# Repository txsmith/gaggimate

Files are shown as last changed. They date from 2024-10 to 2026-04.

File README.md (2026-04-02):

<p align="center">
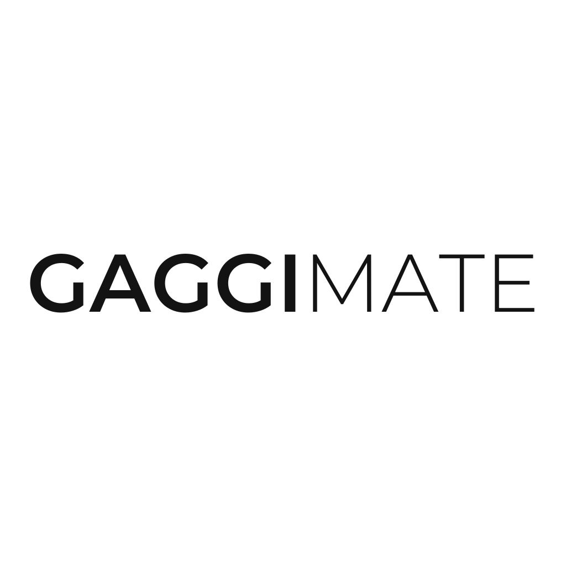
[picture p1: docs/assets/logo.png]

<br />
  

[][cc-by-nc-sa]
[][sonar-url]
[][sonar-url]
[][sonar-url]

</p>

This project upgrades a Gaggia espresso machine with smart controls to improve your coffee-making experience. By adding a display and custom electronics, you can monitor and control the machine more easily.

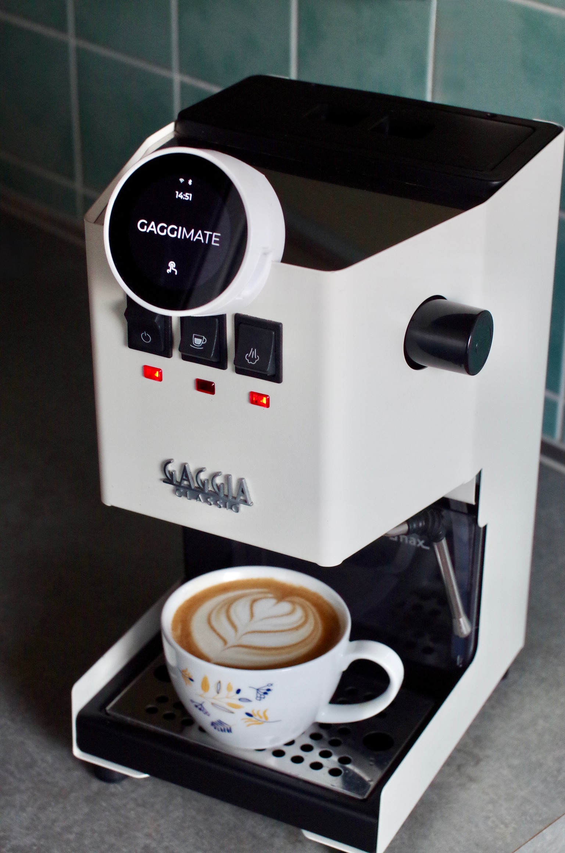
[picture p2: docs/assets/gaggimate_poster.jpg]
Gaggia Classic Installation


## Features

- **Temperature Control**: Monitor the boiler temperature to ensure optimal brewing conditions.
- **Brew timer**: Set a target duration and run the brewing for the specific time.
- **Steam and Hot Water mode**: Control the pump and valve to run the respective task.
- **Safety Features**: Automatic shutoff if the system becomes unresponsive or overheats.
- **User Interface**: Simple, intuitive display to control and monitor the machine.

## Screenshots and Images

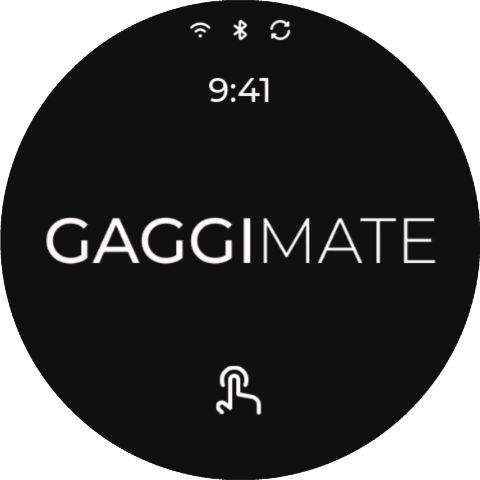
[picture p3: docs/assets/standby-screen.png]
Standby Screen

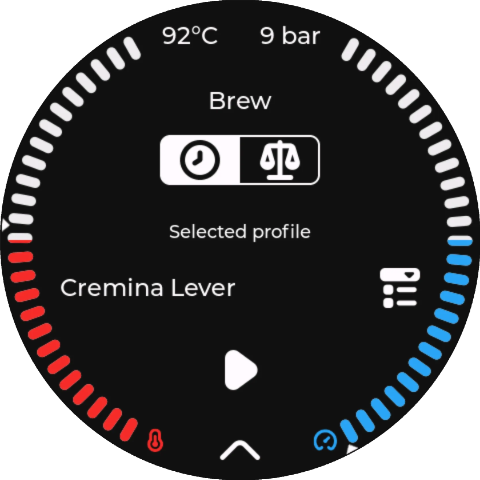
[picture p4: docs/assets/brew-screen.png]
Brew Screen

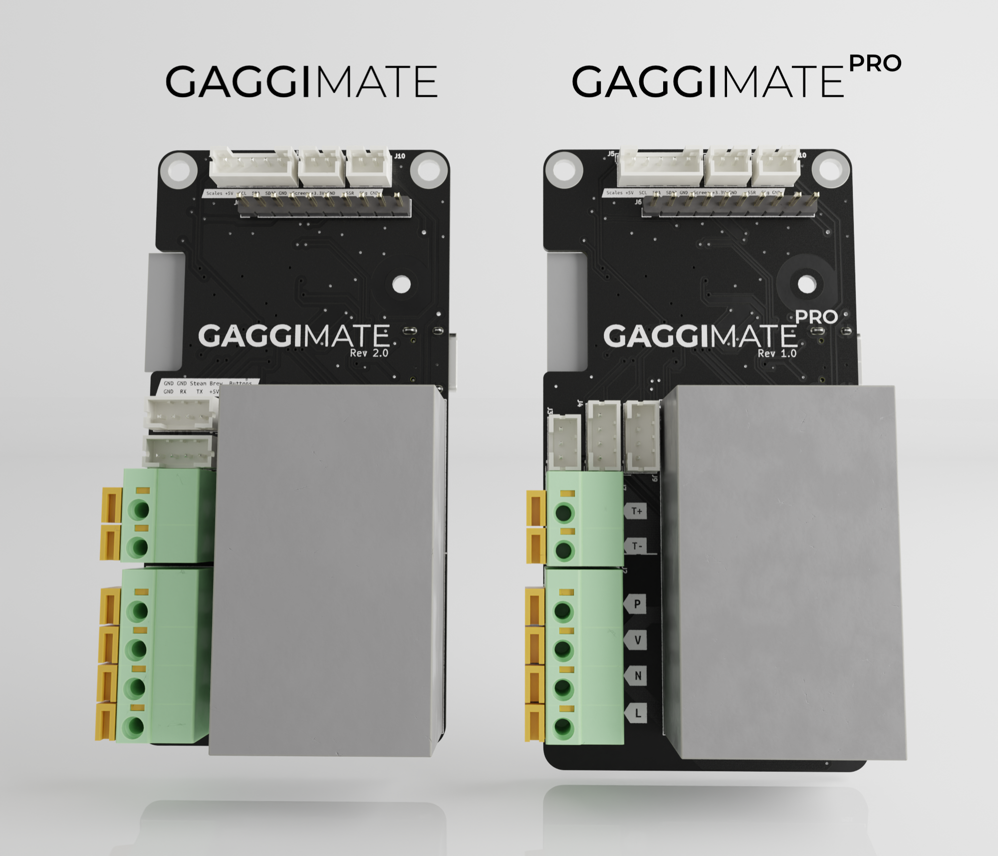
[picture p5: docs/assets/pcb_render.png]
PCB Render


### How to buy

You can buy your kit on https://shop.gaggimate.eu/

## How It Works

The display allows you to control the espresso machine and see live temperature updates. If the machine becomes unresponsive or the temperature goes too high, it will automatically turn off for safety.

## Docs

The docs were moved to [https://gaggimate.eu/](https://gaggimate.eu/). You can find all sourcing and assembly information there.
Additional documentation for the WebSocket API can be found in [docs/websocket-api.yaml](docs/websocket-api.yaml).

## License

This work is licensed under CC BY-NC-SA 4.0. To view a copy of this license, visit https://creativecommons.org/licenses/by-nc-sa/4.0/

[sonar-violations]: https://img.shields.io/sonar/blocker_violations/jniebuhr_gaggimate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
[sonar-shield]: https://img.shields.io/sonar/quality_gate/jniebuhr_gaggimate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
[sonar-tech-debt]: https://img.shields.io/sonar/tech_debt/jniebuhr_gaggimate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
[sonar-url]: https://sonarcloud.io/project/overview?id=jniebuhr_gaggimate
[cc-by-nc-sa]: http://creativecommons.org/licenses/by-nc-sa/4.0/
[cc-by-nc-sa-image]: https://licensebuttons.net/l/by-nc-sa/4.0/88x31.png
[cc-by-nc-sa-shield]: https://img.shields.io/badge/License-CC%20BY--NC--SA%204.0-lightgrey.svg?style=for-the-badge

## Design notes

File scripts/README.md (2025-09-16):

# Gaggimate Development Scripts

This directory contains various utility scripts for development and debugging.

## Core Dump Analysis

### `analyze_coredump.py` / `analyze_coredump.sh`

Automated ESP32 core dump analysis for PlatformIO projects.

**Features:**
- Automatically extracts ELF core dump from ESP32 proprietary format
- Uses ESP-IDF GDB tools for detailed analysis
- Shows exact crash location with line numbers
- Displays full call stack (backtrace)
- Shows register values at time of crash
- Lists all threads and their states
- Provides actionable debugging recommendations

**Usage:**
```bash
# Python script (direct)
python3 scripts/analyze_coredump.py <coredump_file> [environment]

# Shell wrapper (simpler)
./scripts/analyze_coredump.sh <coredump_file> [environment]
```

**Examples:**
```bash
# Analyze core dump with default environment (display)
python3 scripts/analyze_coredump.py ~/Downloads/coredump.bin

# Analyze core dump with specific environment
python3 scripts/analyze_coredump.py ~/Downloads/coredump.bin display
python3 scripts/analyze_coredump.py ~/Downloads/coredump.bin controller
python3 scripts/analyze_coredump.py ~/Downloads/coredump.bin display-headless

# Using shell wrapper
./scripts/analyze_coredump.sh ~/Downloads/coredump.bin
./scripts/analyze_coredump.sh ~/Downloads/coredump.bin controller
```

**Requirements:**
- ESP-IDF tools installed (automatic with VS Code ESP-IDF extension)
- PlatformIO project with built firmware
- Python 3.x

**Sample Output:**
```
🚀 ESP32 Core Dump Analyzer
==================================================
Core dump: /home/user/Downloads/coredump.bin
Environment: display

✅ Found GDB: xtensa-esp32s3-elf-gdb
✅ ELF header found at offset: 20
✅ Extracted ELF core dump to: /tmp/tmpXXXXX.elf

================================================================================
🔍 CORE DUMP ANALYSIS
================================================================================
#0  DefaultUI::updateStatusScreen (this=0x3fced5e4) at src/display/ui/default/DefaultUI.cpp:655
655         if (process->getType() != MODE_BREW) {
#1  0x420254df in DefaultUI::loop (this=0x3fced5e4) at src/display/ui/default/DefaultUI.cpp:230
#2  0x42025510 in DefaultUI::loopTask (arg=0x3fced5e4) at src/display/ui/default/DefaultUI.cpp:766
...
```

**Getting Core Dumps:**
1. **From Web Interface:** Visit `http://your-device-ip/`, go to System & Updates, click "Download Core Dump"
2. **From Serial Monitor:** Core dumps appear in terminal output after crashes
3. **From Device Flash:** Use `esptool.py` to read core dump partition

**Interactive Analysis:**
For deeper debugging, use the extracted ELF file with GDB interactively:
```bash
xtensa-esp32s3-elf-gdb .pio/build/display/firmware.elf
(gdb) core-file /tmp/extracted_coredump.elf
(gdb) bt
(gdb) list
(gdb) info locals
(gdb) print variable_name
```

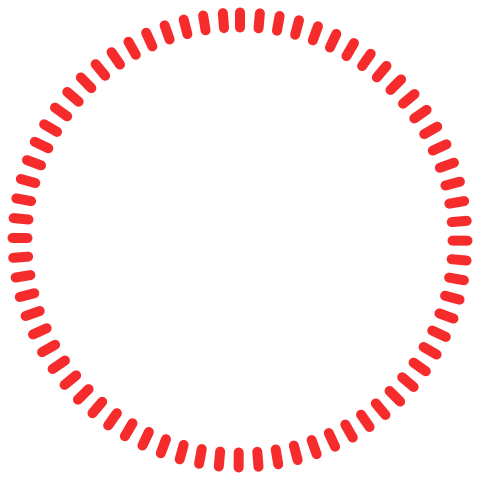
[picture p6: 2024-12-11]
ui/assets/gauge-fill.png

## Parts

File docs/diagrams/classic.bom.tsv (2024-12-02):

Id | Description | Qty | Unit | Designators
1 | Cable, 1 x 18 AWG | 0 | m | EARTH, HEATER_BRIDGE, LINE, MAIN_POWER, NEUTRAL, NEUTRAL_FUSED
2 | Cable, 2 x 18 AWG | 0 | m | SSR_CONN, SWITCHED
3 | Cable, 2 x 22 AWG | 0 | m | DISPLAY_PWR, SSR_SIGNAL
4 | Cable, 4 x 22 AWG | 0 | m | BUTTONS
5 | Connector, 2 pins | 1 |  | THERMAL_FUSE
6 | Connector, 3 pins | 1 |  | SOCKET
7 | Connector, 6.35mm Female Spade / Piggyback, 2 pins | 1 |  | POWER_SWITCH
8 | Connector, 6.35mm Spade, female, 2 pins | 3 |  | BREW_SWITCH, PUMP, STEAM_SWITCH
9 | Connector, 6.35mm Spade, female, 3 pins | 1 |  | SOLENOID
10 | Connector, Boiler grounding | 1
11 | Connector, Bullet connectors, 4 pins | 1 |  | HEATER
12 | Connector, Case grounding | 1
13 | Connector, Crimp ferrule, 4 pins | 1 |  | SOLID_STATE_RELAY
14 | Connector, Crimp ferrule, 5 pins | 1 |  | BOARD_HV
15 | Connector, Grove Connector, 4 pins | 1 |  | DISPLAY
16 | Connector, JST XH, female, 8 pins | 1 |  | BOARD_LV

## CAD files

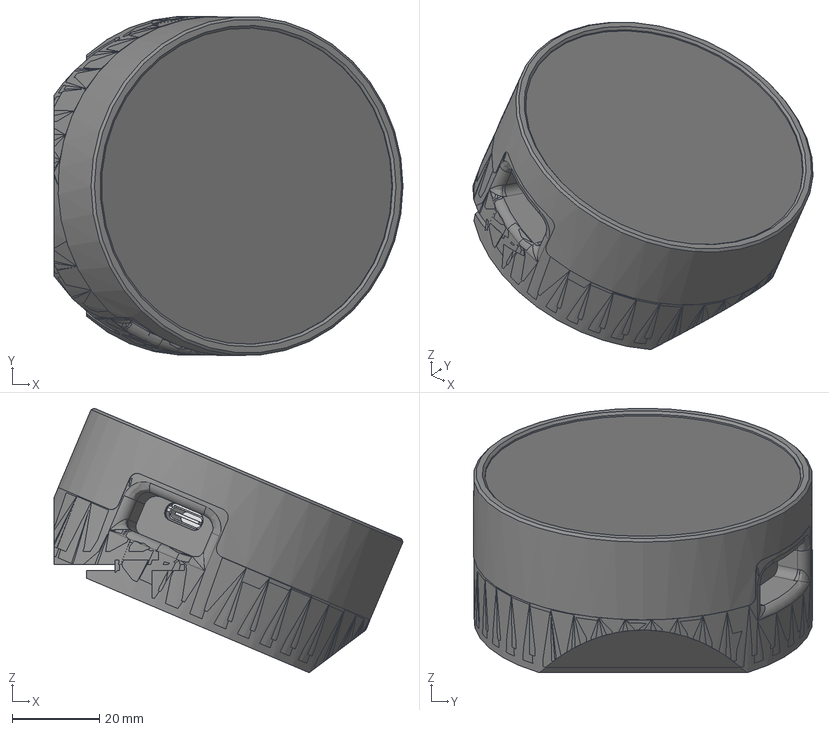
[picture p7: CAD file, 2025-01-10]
cad/Angled Display Case.step
80.1 x 77.9 x 60.7 mm
Case Front
Case Back Rancilio
LCD_BH021
T_RGB-V1_0
T_RGB_COVA
Case Back GCP
Case Back GC

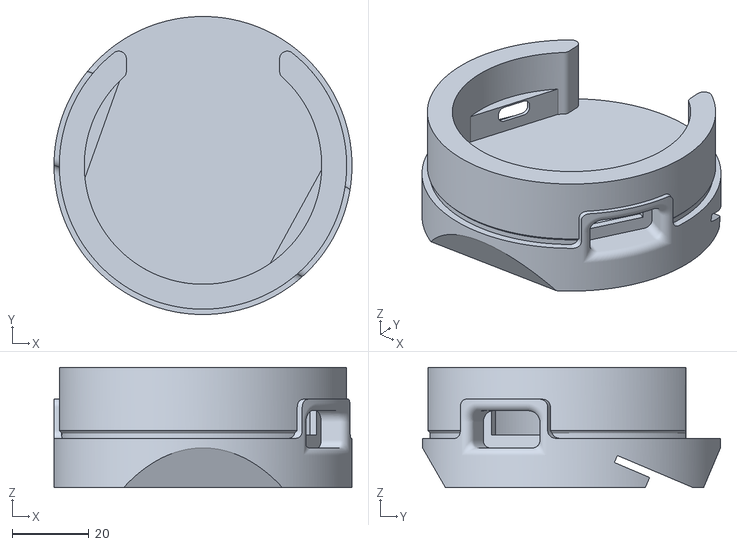
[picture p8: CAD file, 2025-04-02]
stls/display/case_back_rancilio_silvia.stl
77.8 x 77.8 x 31.4

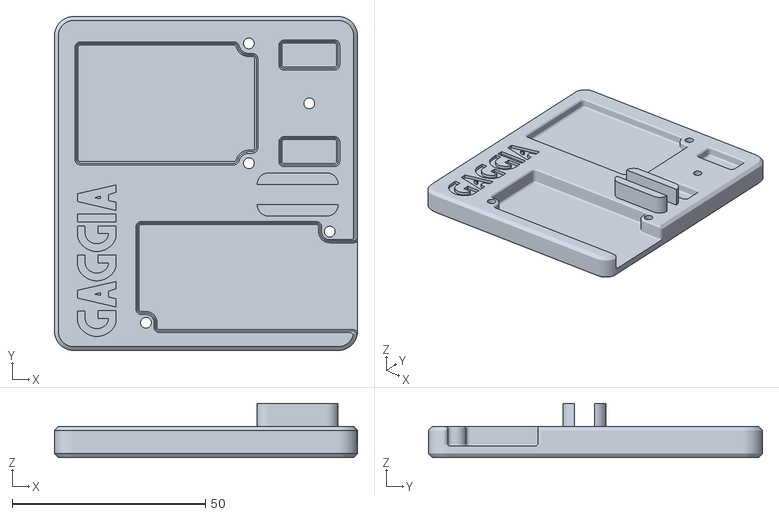
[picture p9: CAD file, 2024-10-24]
stls/lego/electronics_mount.stl
78.5 x 86.5 x 14.0

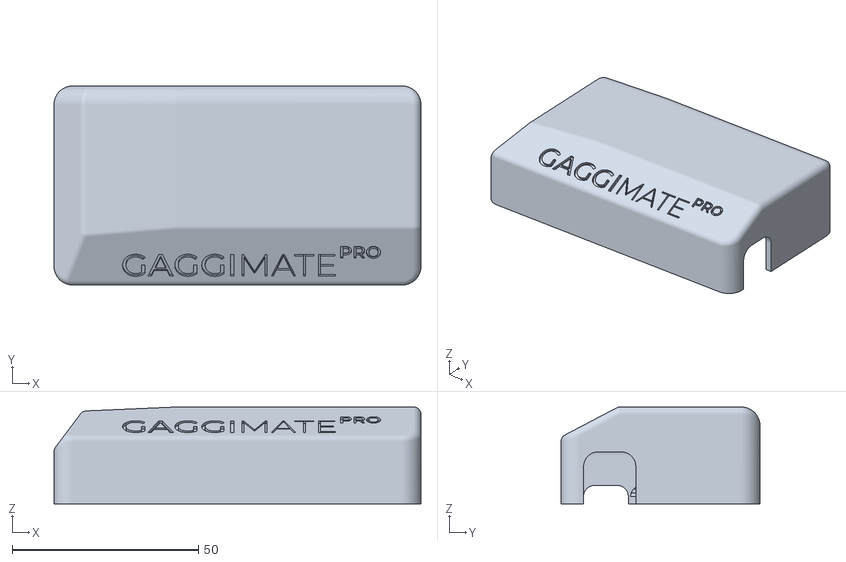
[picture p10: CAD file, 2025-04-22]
stls/pcb/gaggimate-pro-rev1/pcb_cover_clipped_[support].stl
98.4 x 53.4 x 26.0

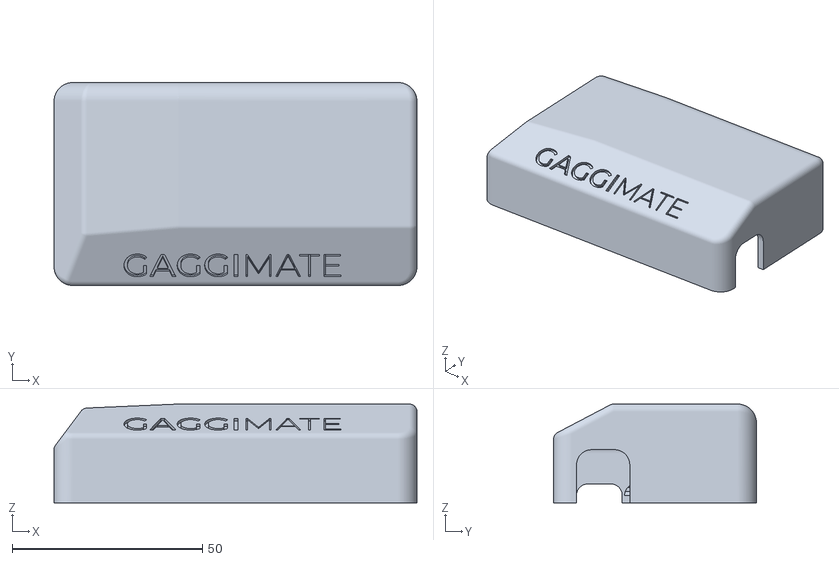
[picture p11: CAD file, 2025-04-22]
stls/pcb/gaggimate-standard-rev2/pcb_cover_clipped_[support].stl
95.4 x 53.4 x 26.0

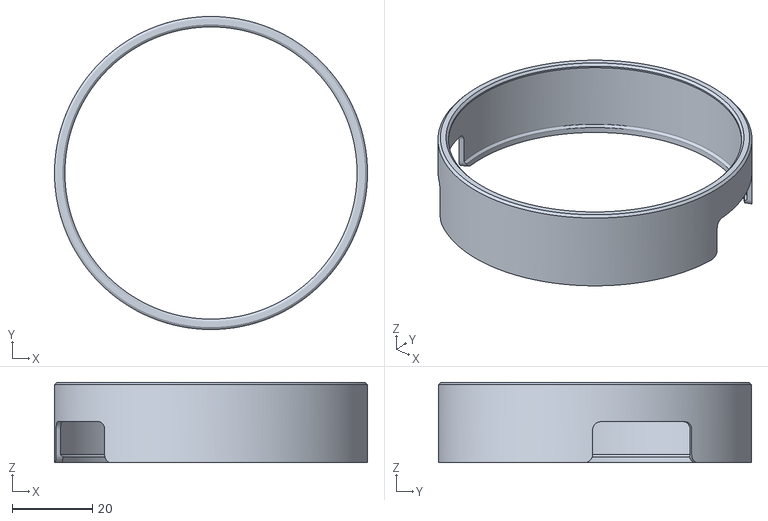
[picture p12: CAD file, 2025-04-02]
stls/display/case_front.stl
77.8 x 77.8 x 20.0

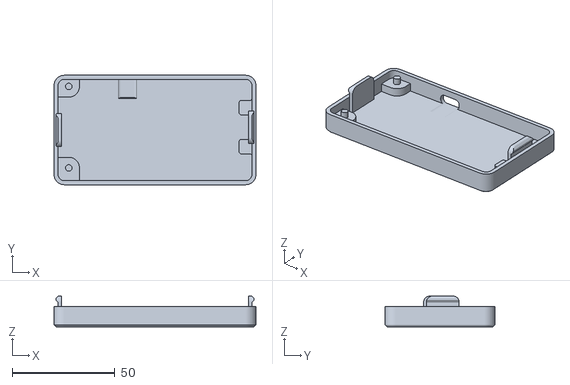
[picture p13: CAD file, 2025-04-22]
stls/pcb/gaggimate-pro-rev1/pcb_base_clipped.stl
98.4 x 53.4 x 15.0

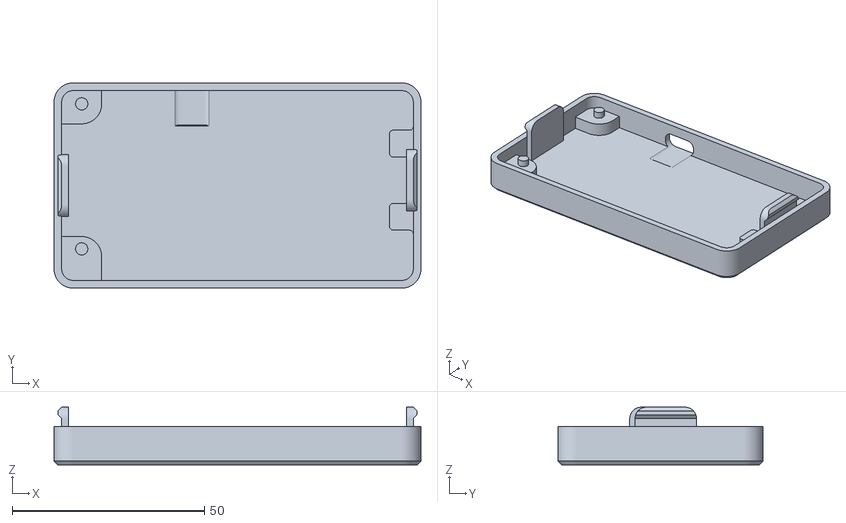
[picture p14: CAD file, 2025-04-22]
stls/pcb/gaggimate-standard-rev2/pcb_base_clipped.stl
95.4 x 53.4 x 15.0

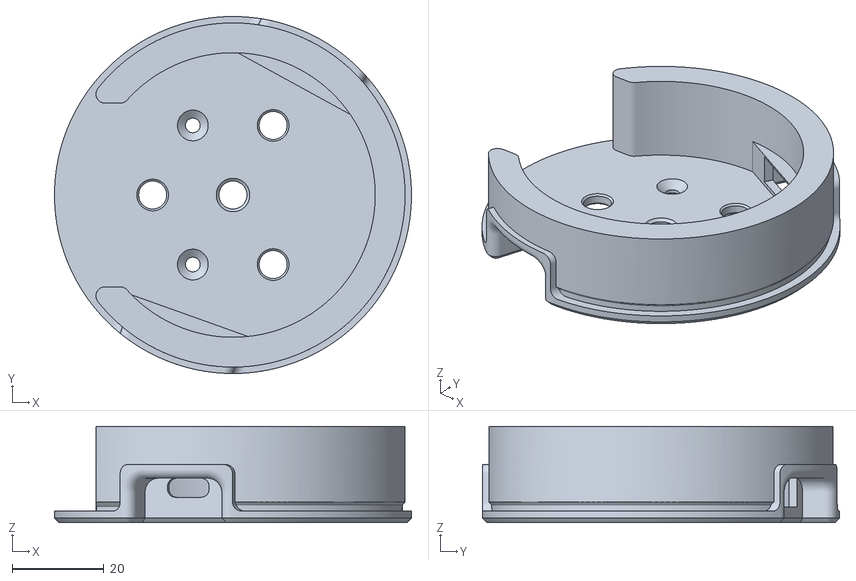
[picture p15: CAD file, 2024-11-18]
stls/display/Alternative backplate/case_back.stl
77.8 x 77.8 x 21.0

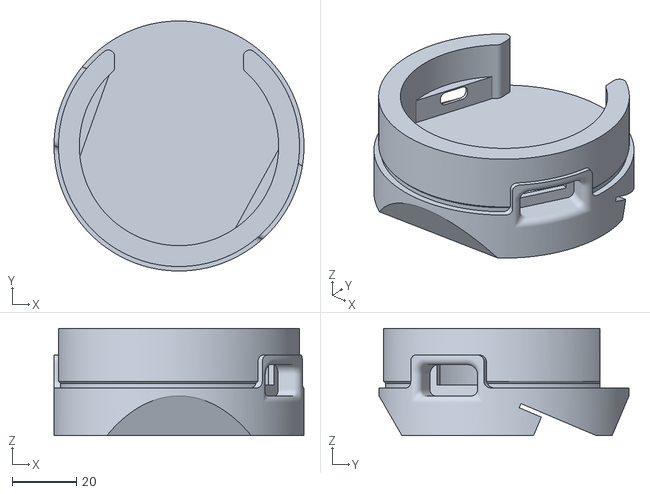
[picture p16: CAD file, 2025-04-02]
stls/display/case_back_gaggia_classic_pro.stl
77.8 x 77.8 x 33.4

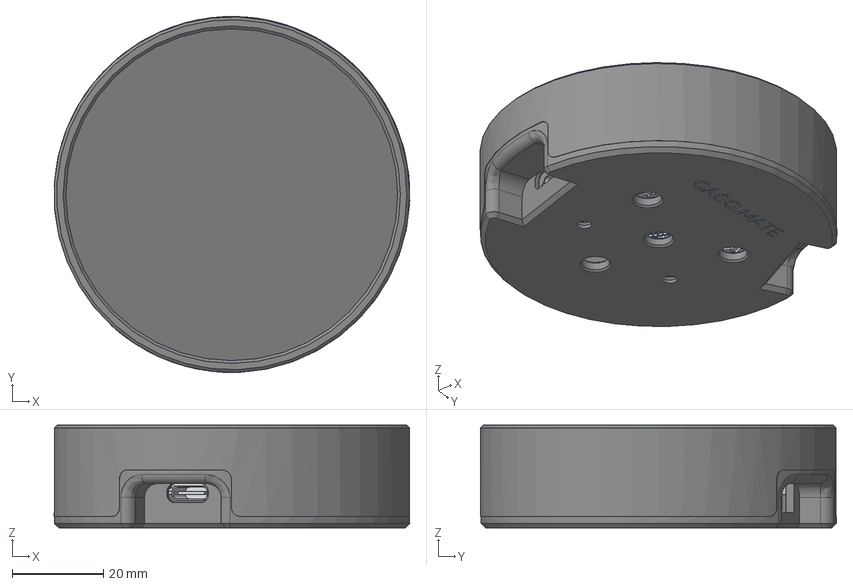
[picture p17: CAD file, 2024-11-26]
cad/Display Case.step
77.8 x 77.9 x 22.5 mm
Case Front
Case Back
LCD_BH021
T_RGB-V1_0
T_RGB_COVA

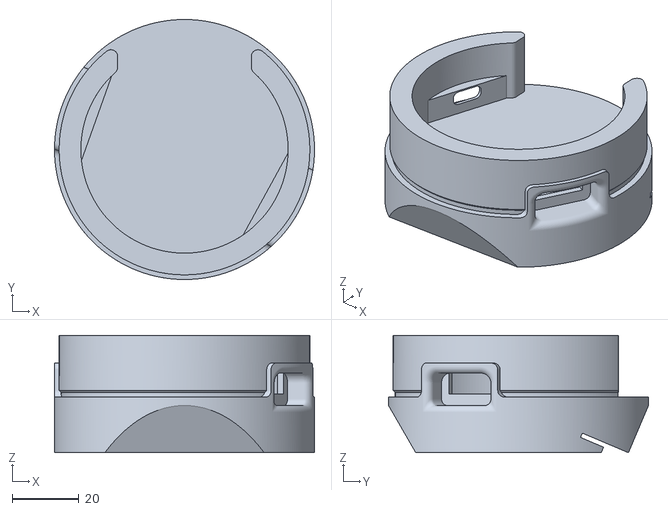
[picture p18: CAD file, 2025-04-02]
stls/display/case_back_gaggia_classic.stl
77.8 x 77.8 x 35.1

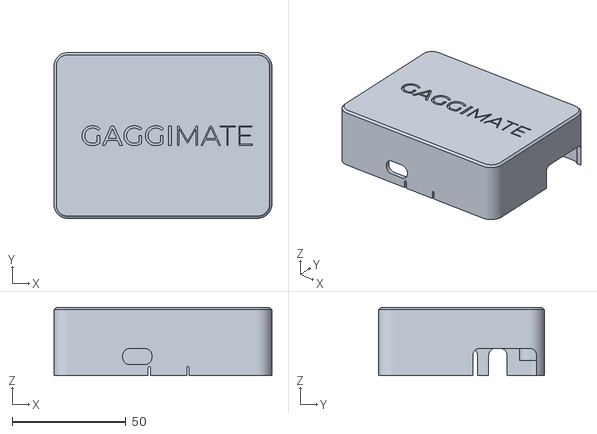
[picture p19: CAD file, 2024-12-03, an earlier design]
stls/pcb/gaggimate-standard-rev1/pcb_clipped_cover.stl
96.0 x 73.0 x 30.0

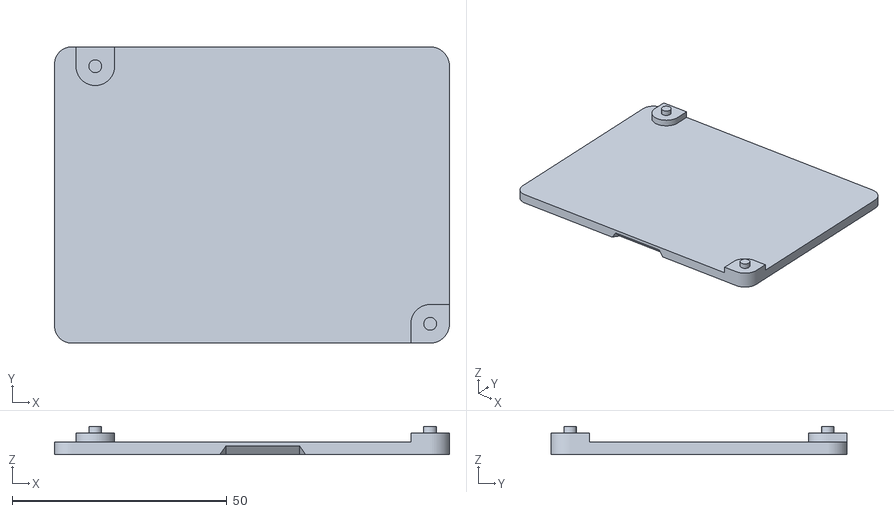
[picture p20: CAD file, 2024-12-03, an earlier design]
stls/pcb/gaggimate-standard-rev1/pcb_clipped_base.stl
92.0 x 69.0 x 6.60

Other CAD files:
stls/display/Alternative backplate/Case-back-withScrewholes.stl.stl
cad/Screen Backplate - no screwholes.step
stls/display/Alternative backplate/Case-back-noScrewholes.stl
cad/Screen Backplate - With screwholes.step
stls/pcb/gaggimate-standard-rev1/pcb_base.stl
stls/pcb/gaggimate-standard-rev1/pcb_cover.stl

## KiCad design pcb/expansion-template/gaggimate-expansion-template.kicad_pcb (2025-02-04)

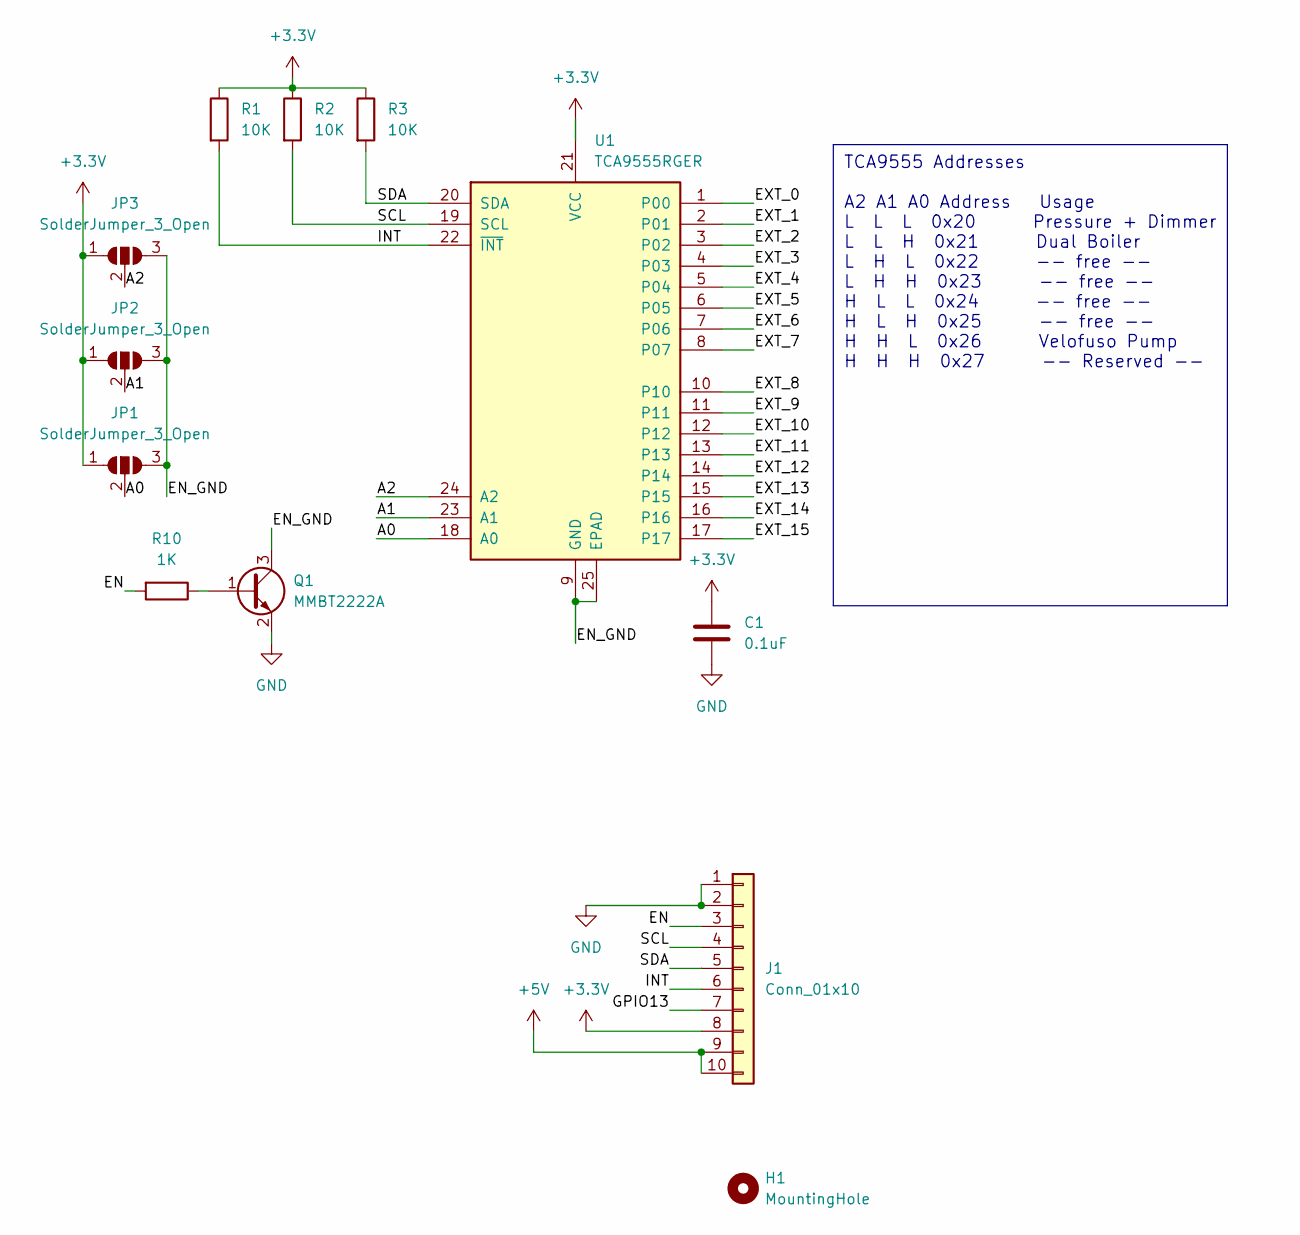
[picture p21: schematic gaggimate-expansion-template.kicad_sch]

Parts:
C1: 0.1uF; C_0603_1608Metric
H1: MountingHole; MountingHole_2.7mm_M2.5
J1: Conn_01x10; PinSocket_1x10_P2.54mm_Vertical
JP1, JP2, JP3: SolderJumper_3_Open; SolderJumper-3_P1.3mm_Open_RoundedPad1.0x1.5mm
Q1: MMBT2222A; SOT-23
R1, R2, R3: 10K; R_0603_1608Metric
R10: 1K; R_0603_1608Metric
U1: TCA9555RGER; VQFN-24-1EP_4x4mm_P0.5mm_EP2.45x2.45mm

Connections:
+3.3V: C1.1, J1.8, JP1.1 (A), JP2.1 (A), JP3.1 (A), R1.1, R2.1, R3.1, U1.21 (VCC)
+5V: J1.9, J1.10
/A0: JP1.2 (C), U1.18 (A0)
/A1: JP2.2 (C), U1.23 (A1)
/A2: JP3.2 (C), U1.24 (A2)
/EN: J1.3, R10.2
/EN_GND: JP1.3 (B), JP2.3 (B), JP3.3 (B), Q1.3 (C), U1.9 (GND), U1.25 (EPAD)
/EXT_0: U1.1 (P00)
/EXT_1: U1.2 (P01)
/EXT_2: U1.3 (P02)
/EXT_3: U1.4 (P03)
/EXT_4: U1.5 (P04)
/EXT_5: U1.6 (P05)
/EXT_6: U1.7 (P06)
/EXT_7: U1.8 (P07)
/EXT_8: U1.10
/EXT_9: U1.11
/EXT_10: U1.12
/EXT_11: U1.13
/EXT_12: U1.14
/EXT_13: U1.15
/EXT_14: U1.16
/EXT_15: U1.17
/GPIO13: J1.7
/INT: J1.6, R1.2, U1.22 (~INT)
/SCL: J1.4, R2.2, U1.19 (SCL)
/SDA: J1.5, R3.2, U1.20 (SDA)
GND: C1.2, J1.1, J1.2, Q1.2 (E)
unnamed: Q1.1 (B), R10.1

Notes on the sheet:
TCA9555 Addresses A2 A1 A0 Address Usage L L L 0x20 Pressure + Dimmer L L H 0x21 Dual Boiler L H L 0x22 -- free -- L H H 0x23 -- free -- H L L 0x24 -- free -- H L H 0x25 -- free -- H H L 0x26 Velofuso Pump H H H 0x27 -- Reserved --

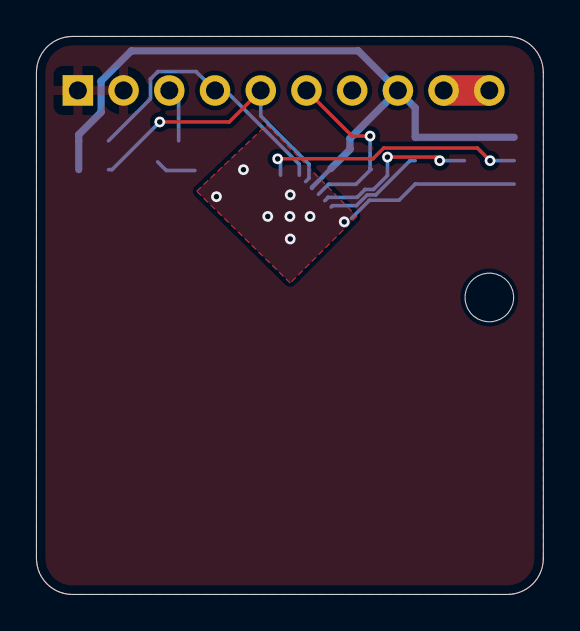
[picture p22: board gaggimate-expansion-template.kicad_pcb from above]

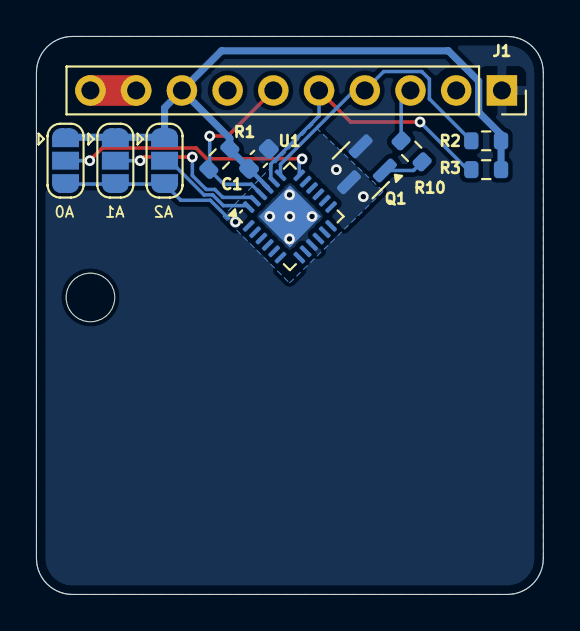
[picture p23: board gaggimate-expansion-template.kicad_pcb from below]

Board: 2 copper layers, 28.2 x 31.0 mm, 12 parts (11 on the bottom side), 12 nets.

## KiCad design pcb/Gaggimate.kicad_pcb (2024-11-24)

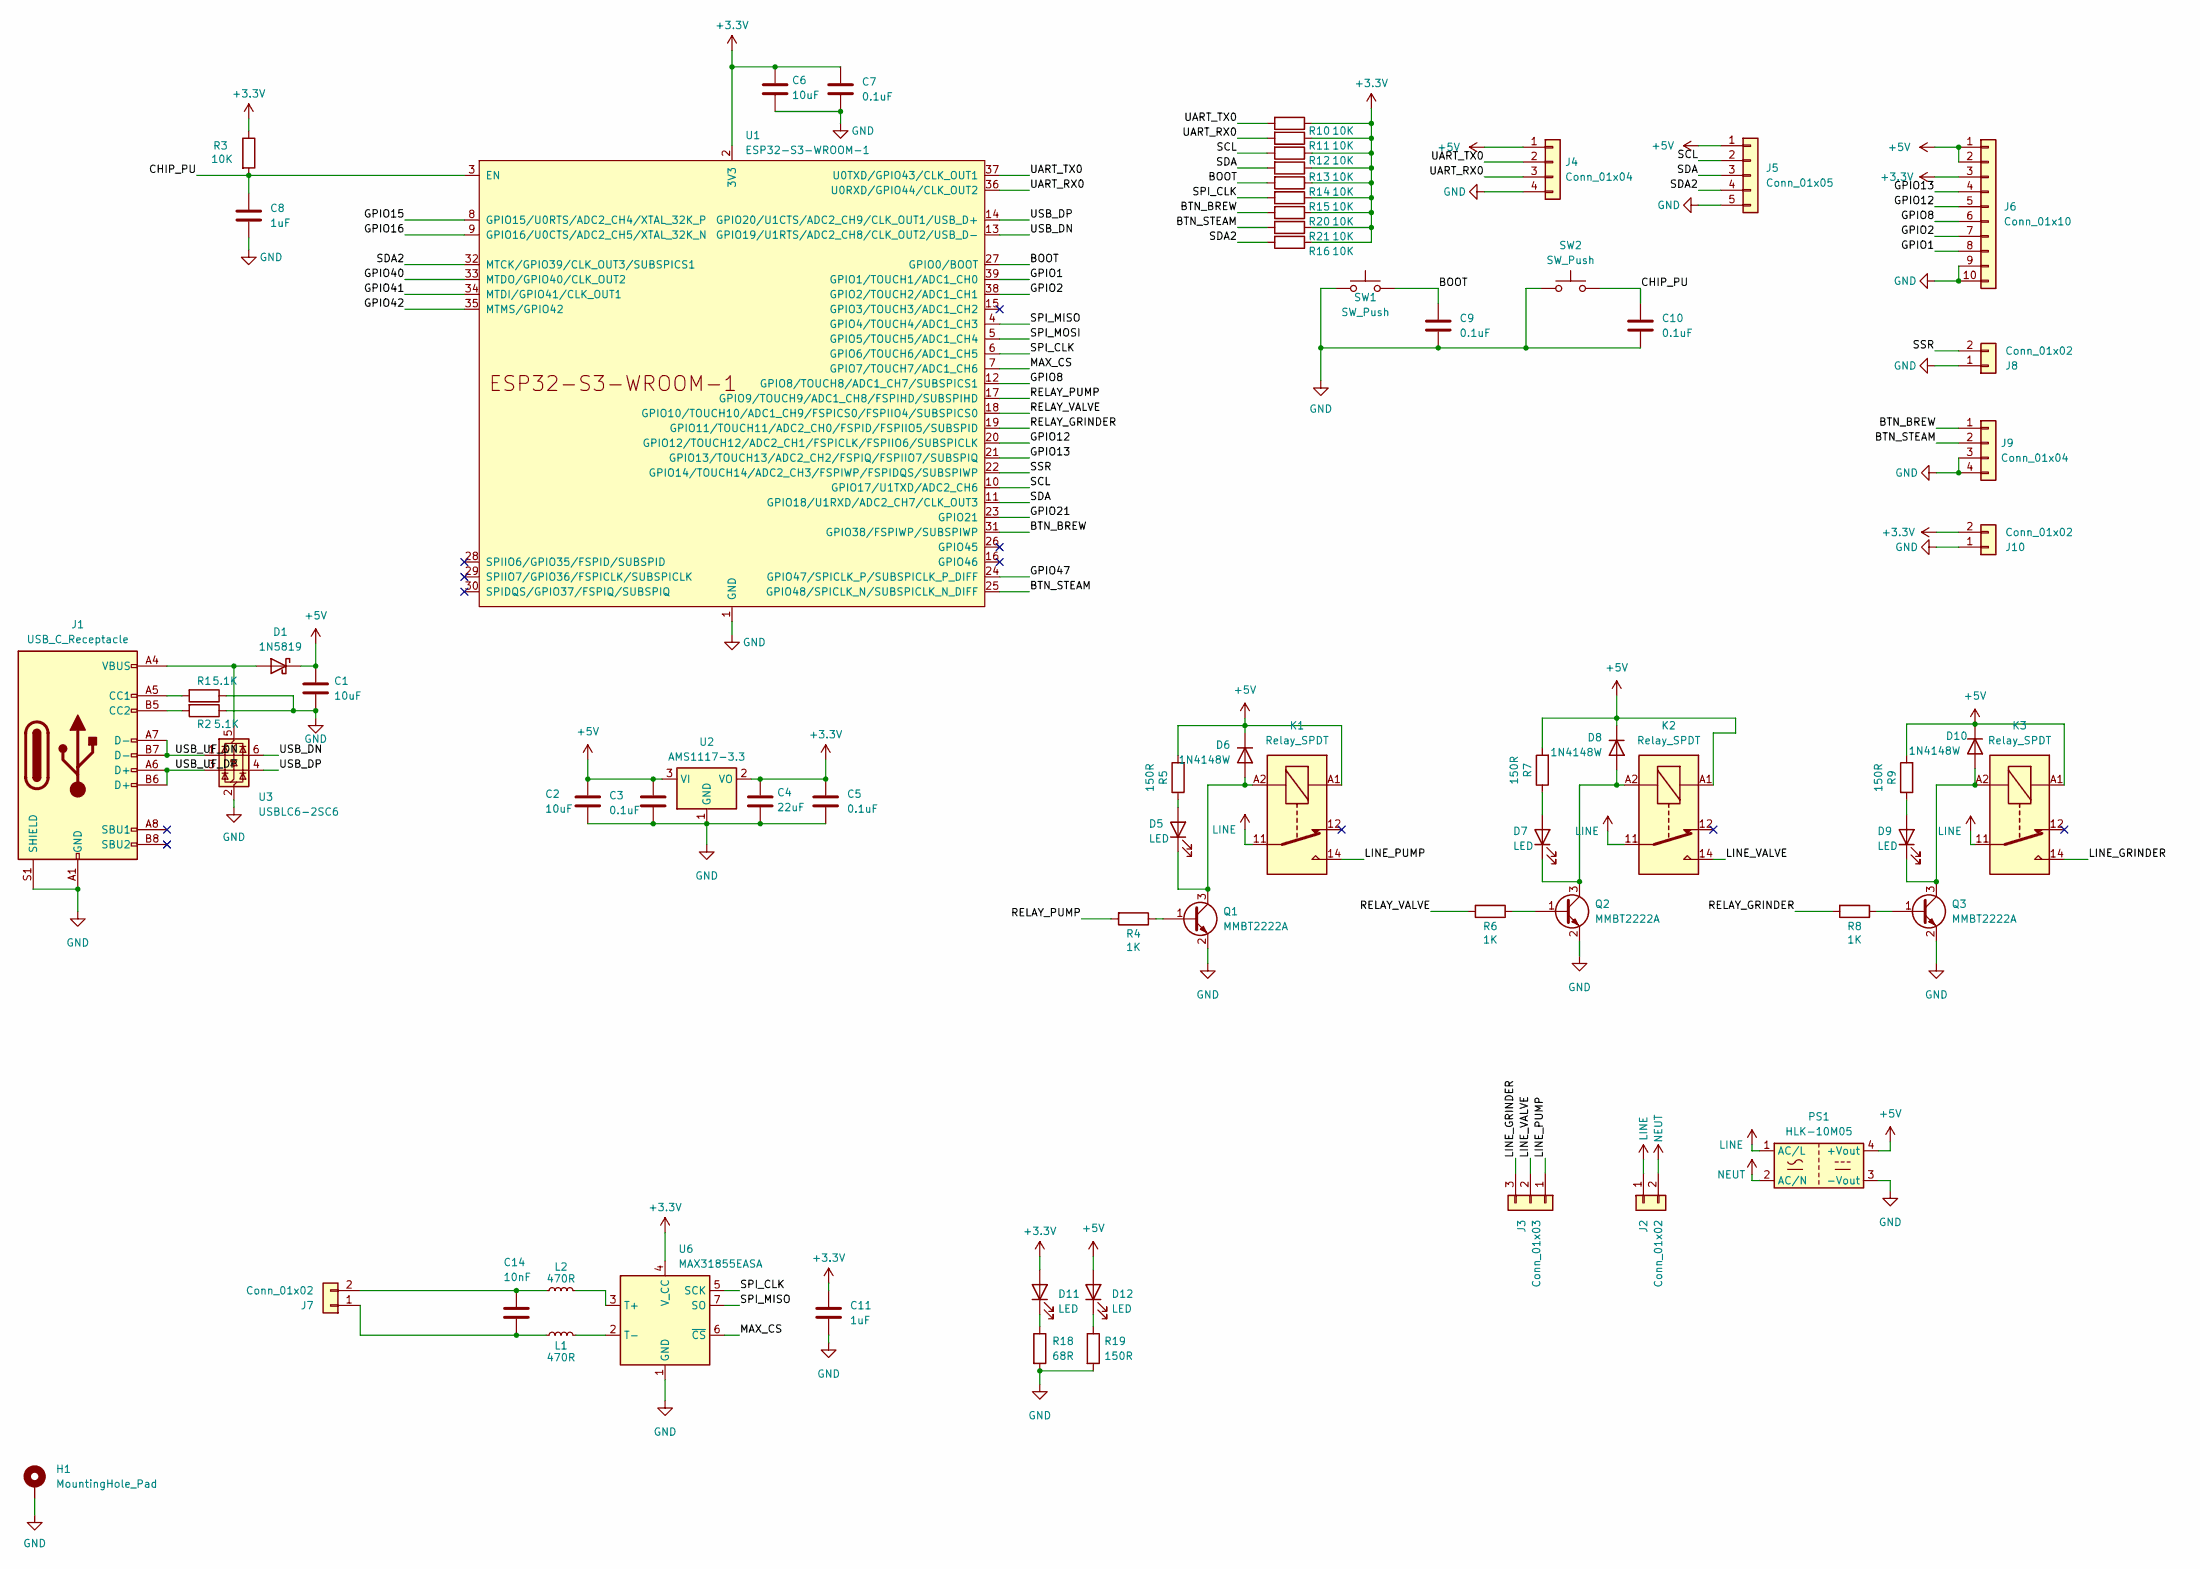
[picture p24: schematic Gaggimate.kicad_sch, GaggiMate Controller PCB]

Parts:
C1, C2, C6: 10uF; C_0805_2012Metric; LCSC C15850
C3, C5, C7, C9, C10: 0.1uF; C_0805_2012Metric; LCSC C49678
C4: 22uF; C_0805_2012Metric; LCSC C45783
C8, C11: 1uF; C_0805_2012Metric; LCSC C28323
C14: 10nF; C_0805_2012Metric; LCSC C1710
D1: 1N5819; D_SOD-123; LCSC C2891704
D5, D7, D9, D11, D12: LED; LED_0805_2012Metric; LCSC C84256
D6, D8, D10: 1N4148W; D_SOD-123; LCSC C81598
H1: MountingHole_Pad; MountingHole_3.2mm_M3_DIN965_Pad_TopBottom
J1: USB_C_Receptacle; USB_C_Receptacle_HRO_TYPE-C-31-M-12; LCSC C165948
J2: Conn_01x02; TerminalBlock_bornier-2_P5.08mm; LCSC C409161
J3: Conn_01x03; TerminalBlock_bornier-3_P5.08mm; LCSC C409163
J4, J9: Conn_01x04; JST_XH_B4B-XH-A_1x04_P2.50mm_Vertical; LCSC C144395
J5: Conn_01x05; JST_XH_B5B-XH-A_1x05_P2.50mm_Vertical
J6: Conn_01x10; PinHeader_1x10_P2.54mm_Vertical; LCSC C5383117
J7: Conn_01x02; TerminalBlock_Phoenix_PT-1,5-2-3.5-H_1x02_P3.50mm_Horizontal; LCSC C415432
J8, J10: Conn_01x02; JST_XH_B2B-XH-A_1x02_P2.50mm_Vertical; LCSC C158012
K1, K2, K3: Relay_SPDT; Relay_SPDT_Finder_36.11; LCSC C35449
L1, L2: 470R; L_0603_1608Metric; LCSC C413961
PS1: HLK-10M05; Converter_ACDC_HiLink_HLK-10Mxx; LCSC C403745
Q1, Q2, Q3: MMBT2222A; SOT-23; LCSC C916372
R1, R2: 5.1K; R_0805_2012Metric; LCSC C27834
R3, R10, R11, R12, R13, R14, R15, R16, R20, R21: 10K; R_0805_2012Metric; LCSC C17414
R4, R6, R8: 1K; R_0805_2012Metric; LCSC C17513
R5, R7, R9, R19: 150R; R_0805_2012Metric; LCSC C17471
R18: 68R; R_0805_2012Metric; LCSC C17802
SW1, SW2: SW_Push; SW_SPST_SKQG_WithStem; LCSC C116647
U1: ESP32-S3-WROOM-1; LCSC C2913201
U2: AMS1117-3.3; SOT-223-3_TabPin2; LCSC C6186
U3: USBLC6-2SC6; SOT-23-6; LCSC C2827654
U6: MAX31855EASA; SOIC-8_3.9x4.9mm_P1.27mm; LCSC C52028

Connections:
+3.3V: C4.1, C5.1, C6.1, C7.1, C11.1, D11.2 (A), J6.3, J10.2, R3.1, R10.1, R11.1, R12.1, R13.1, R14.1, R15.1, R16.1, R20.1, R21.1, U1.2 (3V3), U2.2 (VO), U6.4 (V_CC)
+5V: C1.1, C2.1, C3.1, D1.1 (K), D6.1 (K), D8.1 (K), D10.1 (K), D12.2 (A), J4.1, J5.1, J6.1, J6.2, K1.A1, K2.A1, K3.A1, PS1.4 (+Vout), R5.2, R7.2, R9.2, U2.3 (VI)
/BOOT: C9.1, R14.2, SW1.2, U1.27 (GPIO0/BOOT)
/BTN_BREW: J9.1, R20.2, U1.31 (GPIO38/FSPIWP/SUBSPIWP)
/BTN_STEAM: J9.2, R21.2, U1.25 (GPIO48/SPICLK_N/SUBSPICLK_N_DIFF)
/CHIP_PU: C8.1, C10.1, R3.2, SW2.2, U1.3 (EN)
/GPIO1: J6.8, U1.39 (GPIO1/TOUCH1/ADC1_CH0)
/GPIO2: J6.7, U1.38 (GPIO2/TOUCH2/ADC1_CH1)
/GPIO8: J6.6, U1.12 (GPIO8/TOUCH8/ADC1_CH7/SUBSPICS1)
/GPIO12: J6.5, U1.20 (GPIO12/TOUCH12/ADC2_CH1/FSPICLK/FSPIIO6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)
/GPIO13: J6.4, U1.21 (GPIO13/TOUCH13/ADC2_CH2/FSPIQ/FSPIIO7/S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)
/GPIO15: U1.8 (GPIO15/U0RTS/ADC2_CH4/XTAL_32K_P)
/GPIO16: U1.9 (GPIO16/U0CTS/ADC2_CH5/XTAL_32K_N)
/GPIO21: U1.23 (GPIO21)
/GPIO40: U1.33 (MTDO/GPIO40/CLK_OUT2)
/GPIO41: U1.34 (MTDI/GPIO41/CLK_OUT1)
/GPIO42: U1.35 (MTMS/GPIO42)
/GPIO47: U1.24 (GPIO47/SPICLK_P/SUBSPICLK_P_DIFF)
/LINE_GRINDER: J3.3, K3.14
/LINE_PUMP: J3.1, K1.14
/LINE_VALVE: J3.2, K2.14
/MAX_CS: U1.7 (GPIO7/TOUCH7/ADC1_CH6), U6.6 (~CS)
/RELAY_GRINDER: R8.2, U1.19 (GPIO11/TOUCH11/ADC2_CH0/FSPID/FSPIIO5/S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)
/RELAY_PUMP: R4.2, U1.17 (GPIO9/TOUCH9/ADC1_CH8/FSPIHD/SUBSPIHD)
/RELAY_VALVE: R6.2, U1.18 (GPIO10/TOUCH10/ADC1_CH9/FSPICS0/FSPIIO4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)
/SCL: J5.2, R12.2, U1.10 (GPIO17/U1TXD/ADC2_CH6)
/SDA: J5.3, R13.2, U1.11 (GPIO18/U1RXD/ADC2_CH7/CLK_OUT3)
/SDA2: J5.4, R16.2, U1.32 (MTCK/GPIO39/CLK_OUT3/SUBSPICS1)
/SPI_CLK: R15.2, U1.6 (GPIO6/TOUCH6/ADC1_CH5), U6.5 (SCK)
/SPI_MISO: U1.4 (GPIO4/TOUCH4/ADC1_CH3), U6.7 (SO)
/SPI_MOSI: U1.5 (GPIO5/TOUCH5/ADC1_CH4)
/SSR: J8.2, U1.22 (GPIO14/TOUCH14/ADC2_CH3/FSPIWP/FSPIDQS/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)
/UART_RX0: J4.3, R11.2, U1.36 (U0RXD/GPIO44/CLK_OUT2)
/UART_TX0: J4.2, R10.2, U1.37 (U0TXD/GPIO43/CLK_OUT1)
/USB_DN: U1.13 (GPIO19/U1RTS/ADC2_CH8/CLK_OUT2/USB_D-), U3.6 (I/O1)
/USB_DP: U1.14 (GPIO20/U1CTS/ADC2_CH9/CLK_OUT1/USB_D+), U3.4 (I/O2)
/USB_UF_DN: J1.A7 (D-), J1.B7 (D-), U3.1 (I/O1)
/USB_UF_DP: J1.A6 (D+), J1.B6 (D+), U3.3 (I/O2)
GND: C1.2, C2.2, C3.2, C4.2, C5.2, C6.2, C7.2, C8.2, C9.2, C10.2, C11.2, H1.1, J1.A1 (GND), J1.A12 (GND), J1.B1 (GND), J1.B12 (GND), J1.S1 (SHIELD), J4.4, J5.5, J6.9, J6.10, J8.1, J9.3, J9.4, J10.1, PS1.3 (-Vout), Q1.2 (E), Q2.2 (E), Q3.2 (E), R1.1, R2.1, R18.2, R19.2, SW1.1, SW2.1, U1.1 (GND), U1.40 (GND), U1.41 (GND), U2.1 (GND), U3.2 (GND), U6.1 (GND); also elsewhere on the board
LINE: J2.1, K1.11, K2.11, K3.11, PS1.1 (AC/L)
NEUT: J2.2, PS1.2 (AC/N)
unnamed: D1.2 (A), J1.A4 (VBUS), J1.A9 (VBUS), J1.B4 (VBUS), J1.B9 (VBUS), U3.5 (VBUS)
unnamed: D5.2 (A), R5.1
unnamed: D5.1 (K), D6.2 (A), K1.A2, Q1.3 (C)
unnamed: D7.2 (A), R7.1
unnamed: D7.1 (K), D8.2 (A), K2.A2, Q2.3 (C)
unnamed: D9.2 (A), R9.1
unnamed: D9.1 (K), D10.2 (A), K3.A2, Q3.3 (C)
unnamed: D11.1 (K), R18.1
unnamed: D12.1 (K), R19.1
unnamed: J1.A5 (CC1), R1.2
unnamed: J1.B5 (CC2), R2.2
unnamed: C14.2, J7.1, L1.1
unnamed: C14.1, J7.2, L2.1
unnamed: Q1.1 (B), R4.1
unnamed: Q2.1 (B), R6.1
unnamed: Q3.1 (B), R8.1
unnamed: L2.2, U6.3 (T+)
unnamed: L1.2, U6.2 (T-)

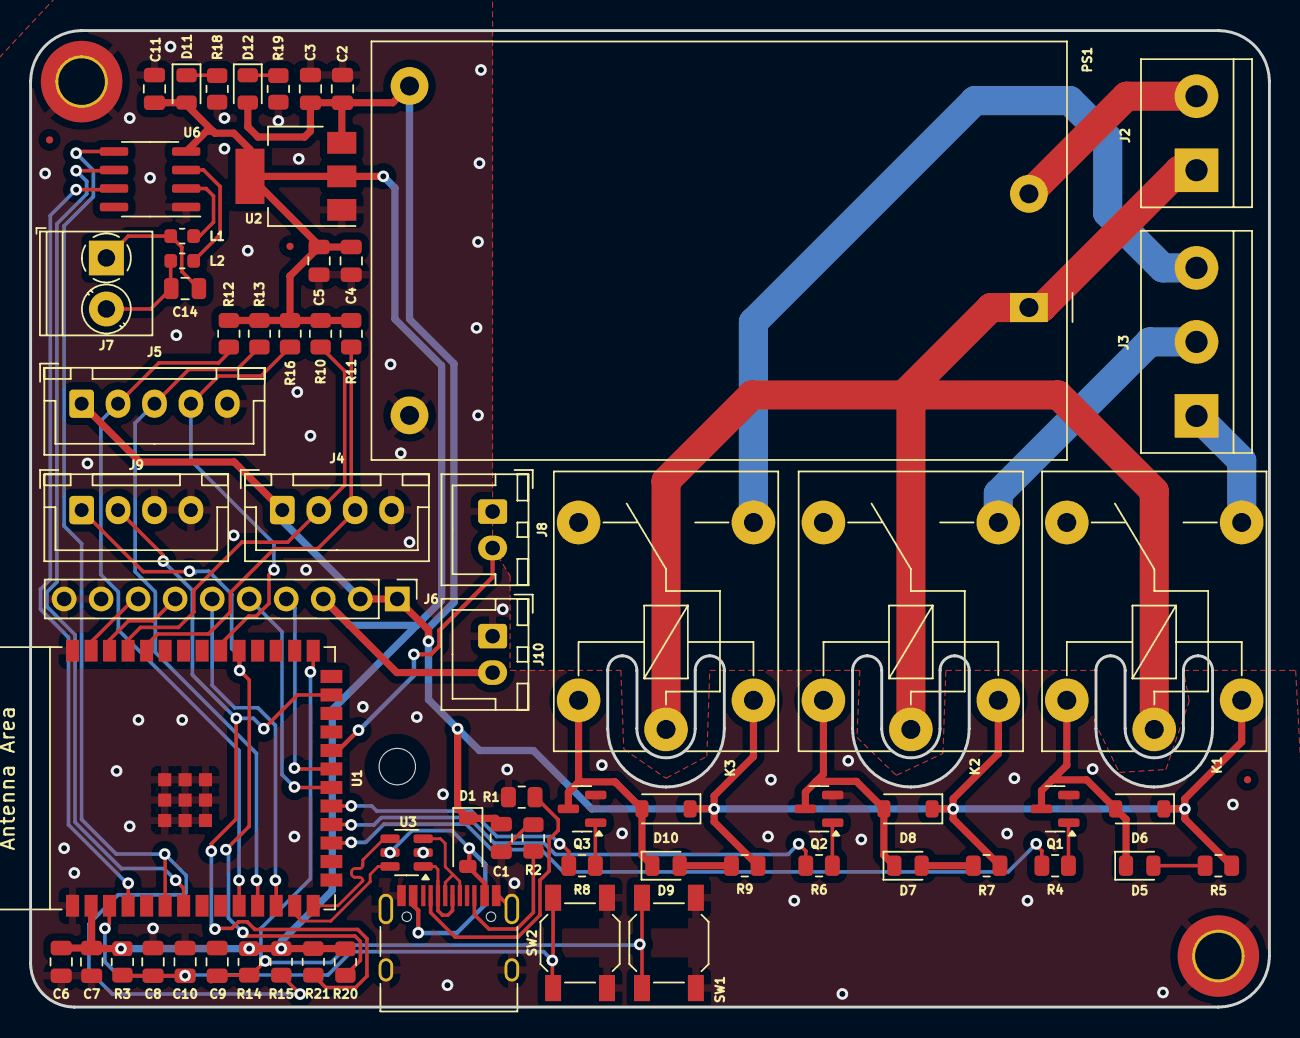
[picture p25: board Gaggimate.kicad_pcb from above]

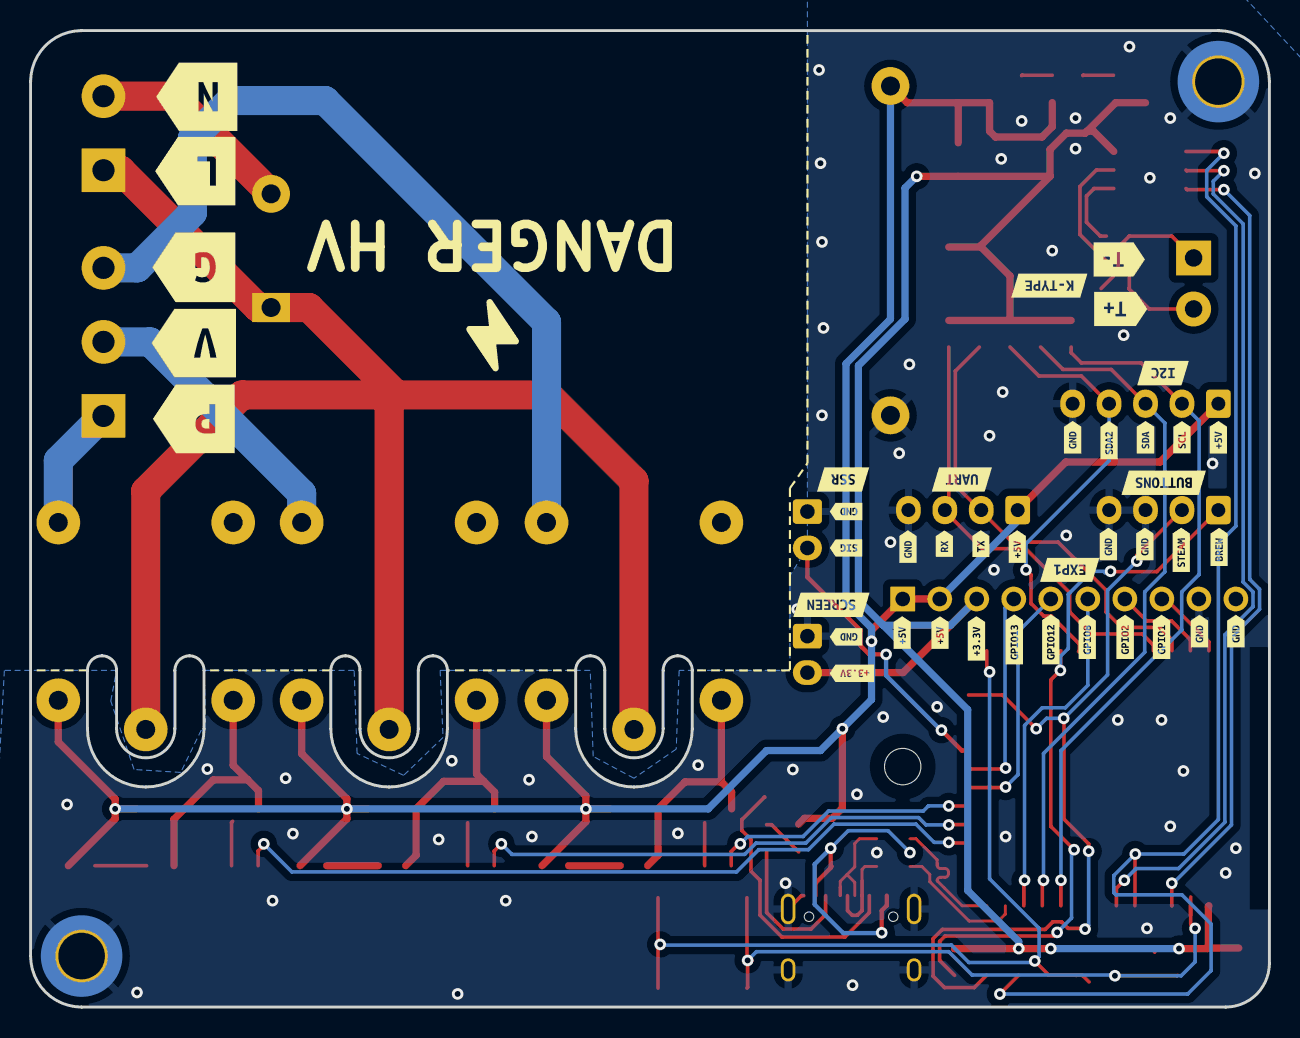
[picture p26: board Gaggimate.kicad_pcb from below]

Board: 2 copper layers, 85.0 x 67.0 mm, 109 parts (41 on the bottom side), 51 nets.

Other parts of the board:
H1#2: MountingHole_Pad; MountingHole_3.2mm_M3_DIN965_Pad_TopBottom
kibuzzard-6735A9F6: G***; kibuzzard-6735A9F6
kibuzzard-6735A9FB: G***; kibuzzard-6735A9FB
kibuzzard-67426AC2: G***; kibuzzard-67426AC2
kibuzzard-673226A0: G***; kibuzzard-673226A0
kibuzzard-673226A8: G***; kibuzzard-673226A8
kibuzzard-673226AF, kibuzzard-673226AF#2: G***; kibuzzard-673226AF
kibuzzard-673226B7: G***; kibuzzard-673226B7
kibuzzard-673226BE: G***; kibuzzard-673226BE
kibuzzard-673226D2: G***; kibuzzard-673226D2
kibuzzard-6732257B: G***; kibuzzard-6732257B
kibuzzard-6732261A: G***; kibuzzard-6732261A
kibuzzard-6732266F: G***; kibuzzard-6732266F
kibuzzard-6732270D: G***; kibuzzard-6732270D
kibuzzard-6732274F: G***; kibuzzard-6732274F
kibuzzard-6732277B: G***; kibuzzard-6732277B
kibuzzard-6732278E: G***; kibuzzard-6732278E
kibuzzard-6732279D: G***; kibuzzard-6732279D
kibuzzard-67322575: G***; kibuzzard-67322575
kibuzzard-67322649, kibuzzard-67322649#2, kibuzzard-67322649#3, kibuzzard-67322649#4, kibuzzard-67322649#5, kibuzzard-67322649#6, kibuzzard-67322649#7, kibuzzard-67322649#8: G***; kibuzzard-67322649
kibuzzard-67322650, kibuzzard-67322650#2, kibuzzard-67322650#3, kibuzzard-67322650#4: G***; kibuzzard-67322650
kibuzzard-67322655: G***; kibuzzard-67322655
kibuzzard-67322681: G***; kibuzzard-67322681
kibuzzard-67322686: G***; kibuzzard-67322686
kibuzzard-67322714: G***; kibuzzard-67322714
kibuzzard-67322749: G***; kibuzzard-67322749
kibuzzard-67322755: G***; kibuzzard-67322755
kibuzzard-67322768: G***; kibuzzard-67322768
kibuzzard-67322783: G***; kibuzzard-67322783
kibuzzard-67322796: G***; kibuzzard-67322796
kibuzzard-67322833: G***; kibuzzard-67322833

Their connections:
GND: H1#2.1; also elsewhere on the board

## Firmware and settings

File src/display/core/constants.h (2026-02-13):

#ifndef CONSTANTS_H
#define CONSTANTS_H

#define PING_INTERVAL 1000
#define PROGRESS_INTERVAL 100
#define HOT_WATER_SAFETY_DURATION_MS 120000
#define STEAM_SAFETY_DURATION_MS 600000
#define BREW_MIN_DURATION_MS 5000
#define BREW_MAX_DURATION_MS 300000
#define BREW_SAFETY_DURATION_MS BREW_MAX_DURATION_MS
#define BREW_MIN_VOLUMETRIC 5.0
#define BREW_MAX_VOLUMETRIC 250.0
#define DEFAULT_STANDBY_TIMEOUT_MS 900000
#define MIN_TEMP 0
#define MAX_TEMP 160
#define DEFAULT_TEMPERATURE_OFFSET 0
#define DEFAULT_PRESSURE_SCALING 16.0f
#define DEFAULT_PID "58.397,1.027,249.055,0.0"
#define DEFAULT_PUMP_MODEL_COEFFS "10.205,5.521"
#define DEFAULT_MDNS_NAME "gaggimate"
#define DEFAULT_OTA_CHANNEL "latest"
#define DEFAULT_TIMEZONE "Europe/Rome"
#define DEFAULT_HOME_ASSISTANT_TOPIC "homeassistant"
#define DEFAULT_STEAM_PUMP_PERCENTAGE 4.f
#define DEFAULT_STEAM_PUMP_CUTOFF 2.f
#define WIFI_CONNECT_ATTEMPTS 20

#define MODE_STANDBY 0
#define MODE_BREW 1
#define MODE_STEAM 2
#define MODE_WATER 3
#define MODE_GRIND 4

// Alt Relay / SSR2 Function constants
#define ALT_RELAY_NONE 0
#define ALT_RELAY_GRIND 1
#define ALT_RELAY_STEAM_BOILER 2

#define WIFI_CONNECT_TIMEOUT_MS 30000
#define DEFAULT_WIFI_AP_TIMEOUT_MS 600000

#endif // CONSTANTS_H

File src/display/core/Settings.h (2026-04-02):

#pragma once
#ifndef SETTINGS_H
#define SETTINGS_H

#include <Arduino.h>
#include <Preferences.h>
#include <display/core/constants.h>
#include <display/core/utils.h>
#include <vector>

#define PREFERENCES_KEY "controller"

struct AutoWakeupSchedule {
    String time;    // HH:MM format
    bool days[7]{}; // [Mon, Tue, Wed, Thu, Fri, Sat, Sun]

    AutoWakeupSchedule() : time("07:00") {
        // Default to all days enabled
        for (int i = 0; i < 7; i++) {
            days[i] = true;
        }
    }

    explicit AutoWakeupSchedule(const String &timeStr) : time(timeStr) {
        // Default to all days enabled
        for (int i = 0; i < 7; i++) {
            days[i] = true;
        }
    }

    [[nodiscard]] bool isDayEnabled(const int dayOfWeek) const {
        // dayOfWeek: 1=Monday, 2=Tuesday, ..., 7=Sunday
        if (dayOfWeek < 1 || dayOfWeek > 7)
            return false;
        return days[dayOfWeek - 1];
    }

    void setDayEnabled(const int dayOfWeek, const bool enabled) {
        // dayOfWeek: 1=Monday, 2=Tuesday, ..., 7=Sunday
        if (dayOfWeek >= 1 && dayOfWeek <= 7) {
            days[dayOfWeek - 1] = enabled;
        }
    }
};

class Settings;
using SettingsCallback = std::function<void(Settings *)>;

class Settings {
  public:
    Settings();

    void batchUpdate(const SettingsCallback &callback);
    void save(bool noDelay = false);

    // Getters and setters
    int getTargetSteamTemp() const { return targetSteamTemp; }
    int getTargetWaterTemp() const { return targetWaterTemp; }
    int getTemperatureOffset() const { return temperatureOffset; }
    float getPressureScaling() const { return pressureScaling; }
    double getTargetGrindVolume() const { return targetGrindVolume; }
    int getTargetGrindDuration() const { return targetGrindDuration; }
    int getStartupMode() const { return startupMode; }
    int getStandbyTimeout() const { return standbyTimeout; }
    double getBrewDelay() const { return brewDelay; }
    double getGrindDelay() const { return grindDelay; }
    bool isDelayAdjust() const { return delayAdjust; }
    String getPid() const { return pid; }
    String getPumpModelCoeffs() const { return pumpModelCoeffs; }
    String getWifiSsid() const { return wifiSsid; }
    String getWifiPassword() const { return wifiPassword; }
    String getMdnsName() const { return mdnsName; }
    bool isHomekit() const { return homekit; }
    bool isVolumetricTarget() const { return volumetricTarget; }
    String getOTAChannel() const { return otaChannel; }
    String getSavedScale() const { return savedScale; }
    bool isBoilerFillActive() const { return boilerFillActive; }
    int getStartupFillTime() const { return startupFillTime; }
    int getSteamFillTime() const { return steamFillTime; }
    bool isSmartGrindActive() const { return smartGrindActive; }
    int getSmartGrindMode() const { return smartGrindMode; }
    String getSmartGrindIp() const { return smartGrindIp; }
    bool isHomeAssistant() const { return homeAssistant; }
    String getHomeAssistantIP() const { return homeAssistantIP; }
    String getHomeAssistantUser() const { return homeAssistantUser; }
    String getHomeAssistantPassword() const { return homeAssistantPassword; }
    int getHomeAssistantPort() const { return homeAssistantPort; }
    String getHomeAssistantTopic() const { return homeAssistantTopic; }
    bool isMomentaryButtons() const { return momentaryButtons; }
    String getTimezone() const { return timezone; }
    bool isClock24hFormat() const { return clock24hFormat; }
    String getSelectedProfile() const { return selectedProfile; }
    std::vector<String> getFavoritedProfiles() const { return favoritedProfiles; }
    std::vector<String> getProfileOrder() const { return profileOrder; }
    int getMainBrightness() const { return mainBrightness; }
    int getStandbyBrightness() const { return standbyBrightness; }
    int getStandbyBrightnessTimeout() const { return standbyBrightnessTimeout; }
    int getWifiApTimeout() const { return wifiApTimeout; }
    float getSteamPumpPercentage() const { return steamPumpPercentage; }
    float getSteamPumpCutoff() const { return steamPumpCutoff; }
    int getThemeMode() const { return themeMode; }
    int getHistoryIndex() const { return historyIndex; }
    int getSunriseR() const { return sunriseR; }
    int getSunriseG() const { return sunriseG; }
    int getSunriseB() const { return sunriseB; }
    int getSunriseW() const { return sunriseW; }
    int getSunriseExtBrightness() const { return sunriseExtBrightness; }
    int getEmptyTankDistance() const { return emptyTankDistance; }
    int getFullTankDistance() const { return fullTankDistance; }
    int getAltRelayFunction() const { return altRelayFunction; }
    bool isAutoWakeupEnabled() const { return autowakeupEnabled; }
    std::vector<AutoWakeupSchedule> getAutoWakeupSchedules() const { return autowakeupSchedules; }
    void setTargetSteamTemp(int target_steam_temp);
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

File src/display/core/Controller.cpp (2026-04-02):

#include "Controller.h"
#include "ArduinoJson.h"
#include "esp_sntp.h"
#include <SD_MMC.h>
#include <SPIFFS.h>
#include <ctime>
#include <display/config.h>
#include <display/core/constants.h>
#include <display/core/process/BrewProcess.h>
#include <display/core/process/GrindProcess.h>
#include <display/core/process/PumpProcess.h>
#include <display/core/process/SteamProcess.h>
#include <display/core/static_profiles.h>
#include <display/core/zones.h>
#include <display/plugins/AutoWakeupPlugin.h>
#include <display/plugins/BLEScalePlugin.h>
#include <display/plugins/BoilerFillPlugin.h>
#include <display/plugins/DebugLogPlugin.h>
#include <display/plugins/HomekitPlugin.h>
#include <display/plugins/LedControlPlugin.h>
#include <display/plugins/MQTTPlugin.h>
#include <display/plugins/ShotHistoryPlugin.h>
#include <display/plugins/SmartGrindPlugin.h>
#include <display/plugins/WebUIPlugin.h>
#include <display/plugins/mDNSPlugin.h>
#ifndef GAGGIMATE_HEADLESS
#include <display/drivers/AmoledDisplayDriver.h>
#include <display/drivers/LilyGoDriver.h>
#include <display/drivers/WaveshareDriver.h>
#endif

const String LOG_TAG = F("Controller");

void Controller::setup() {
    mode = settings.getStartupMode();

    if (!SPIFFS.begin(true)) {
        Serial.println(F("An Error has occurred while mounting SPIFFS"));
    }

#ifndef GAGGIMATE_HEADLESS
    setupPanel();
#endif

    pluginManager = new PluginManager();
#ifndef GAGGIMATE_HEADLESS
    ui = new DefaultUI(this, driver, pluginManager);
    if (driver->supportsSDCard() && driver->installSDCard()) {
        sdcard = true;
        ESP_LOGI(LOG_TAG, "SD Card detected and mounted");
        ESP_LOGI(LOG_TAG, "Used: %lluMB, Capacity: %lluMB", SD_MMC.usedBytes() / 1024 / 1024, SD_MMC.cardSize() / 1024 / 1024);
    }
#endif
    FS *fs = &SPIFFS;
    if (sdcard) {
        fs = &SD_MMC;
    }
    profileManager = new ProfileManager(fs, "/p", settings, pluginManager);
    profileManager->setup();
    if (settings.isHomekit())
        pluginManager->registerPlugin(new HomekitPlugin(settings.getWifiSsid(), settings.getWifiPassword()));
    else
        pluginManager->registerPlugin(new mDNSPlugin());
    if (settings.isBoilerFillActive()) {
        pluginManager->registerPlugin(new BoilerFillPlugin());
    }
    if (settings.isSmartGrindActive()) {
        pluginManager->registerPlugin(new SmartGrindPlugin());
    }
    if (settings.isHomeAssistant()) {
        pluginManager->registerPlugin(new MQTTPlugin());
    }
    pluginManager->registerPlugin(&DebugLog);
    pluginManager->registerPlugin(new WebUIPlugin());
    pluginManager->registerPlugin(&ShotHistory);
    pluginManager->registerPlugin(&BLEScales);
    pluginManager->registerPlugin(new LedControlPlugin());
    pluginManager->registerPlugin(new AutoWakeupPlugin());
    pluginManager->setup(this);

    pluginManager->on("profiles:profile:save", [this](Event const &event) {
        String id = event.getString("id");
        if (id == profileManager->getSelectedProfile().id) {
            this->handleProfileUpdate();
        }
    });

    pluginManager->on("profiles:profile:select", [this](Event const &event) { this->handleProfileUpdate(); });

#ifndef GAGGIMATE_HEADLESS
    ui->init();
#endif
    this->onScreenReady();

    updateLastAction();
    xTaskCreatePinnedToCore(loopTask, "Controller::loopControl", configMINIMAL_STACK_SIZE * 6, this, 1, &taskHandle, 1);
}

void Controller::onScreenReady() { screenReady = true; }

void Controller::onTargetToggle() { settings.setVolumetricTarget(!settings.isVolumetricTarget()); }

void Controller::onTargetChange(ProcessTarget target) { settings.setVolumetricTarget(target == ProcessTarget::VOLUMETRIC); }

void Controller::connect() {
    if (initialized)
        return;
    lastPing = millis();
    connectStartTime = millis();
    pluginManager->trigger("controller:startup");

    setupWifi();
    setupBluetooth();
    pluginManager->on("ota:update:start", [this](Event const &) { this->updating = true; });
    pluginManager->on("ota:update:end", [this](Event const &) { this->updating = false; });

    updateLastAction();
    initialized = true;
}

#ifndef GAGGIMATE_HEADLESS
void Controller::setupPanel() {
    if (LilyGoDriver::getInstance()->isCompatible()) {
        driver = LilyGoDriver::getInstance();
    } else if (AmoledDisplayDriver::getInstance()->isCompatible()) {
        driver = AmoledDisplayDriver::getInstance();
    } else if (WaveshareDriver::getInstance()->isCompatible()) {
        driver = WaveshareDriver::getInstance();
    } else {
        Serial.println("No compatible display driver found");
        delay(10000);
        ESP.restart();
    }
    driver->init();
}
#endif
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

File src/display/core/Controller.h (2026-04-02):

#ifndef CONTROLLER_H
#define CONTROLLER_H

#include "NimBLEClientController.h"
#include "NimBLEComm.h"
#include "PluginManager.h"
#include "Settings.h"
#include <WiFi.h>
#include <display/core/ProfileManager.h>
#include <display/core/process/Process.h>
#ifndef GAGGIMATE_HEADLESS
#include <display/drivers/Driver.h>
#include <display/ui/default/DefaultUI.h>
#endif

const IPAddress WIFI_AP_IP(4, 4, 4, 1); // the IP address the web server, Samsung requires the IP to be in public space
const IPAddress WIFI_SUBNET_MASK(255, 255, 255, 0); // no need to change: https://avinetworks.com/glossary/subnet-mask/

enum class VolumetricMeasurementSource { INACTIVE, FLOW_ESTIMATION, BLUETOOTH };

class Controller {
  public:
    Controller() = default;

    void setup();
    void connect();
    void loop();
    void loopControl();

    void setMode(int newMode);
    void setTargetTemp(float temperature);
    void setPressureScale();
    void setPumpModelCoeffs();
    void setTargetGrindDuration(int duration);
    void setTargetGrindVolume(double volume);

    int getMode() const;

    float getTargetTemp() const;
    int getTargetGrindDuration() const;
    virtual float getCurrentTemp() const { return currentTemp; }
    bool isActive() const;
    bool isGrindActive() const;
    bool isUpdating() const;
    bool isAutotuning() const;
    bool isReady() const;
    bool isVolumetricAvailable() const;
    bool isSDCard() const { return sdcard; }
    virtual float getTargetPressure() const { return targetPressure; }
    virtual float getTargetFlow() const { return targetFlow; }
    virtual float getCurrentPressure() const { return pressure; }
    virtual float getCurrentPuckFlow() const { return currentPuckFlow; }
    virtual float getCurrentPumpFlow() const { return currentPumpFlow; }

    void autotune(int testTime, int samples);
    void startProcess(Process *process);
    Process *getProcess() const { return currentProcess; }
    Process *getLastProcess() const { return lastProcess; }
    Settings &getSettings() { return settings; }
    ProfileManager *getProfileManager() { return profileManager; }
#ifndef GAGGIMATE_HEADLESS
    DefaultUI *getUI() const { return ui; }
#endif
    bool isErrorState() const { return error > 0; }
    int getError() const { return error; }

    // Event callback methods
    void updateLastAction();
    void raiseTemp();
    void lowerTemp();
    void raiseBrewTarget();
    void lowerBrewTarget();
    void raiseGrindTarget();
    void lowerGrindTarget();
    void activate();
    void deactivate();
    void clear();
    void activateGrind();
    void deactivateGrind();
    void activateStandby();
    void deactivateStandby();
    void onOTAUpdate();
    void onScreenReady();
    void onTargetToggle();
    void onTargetChange(ProcessTarget target);
    void onProfileSave() const;
    void onProfileSaveAsNew();
    void onVolumetricMeasurement(double measurement, VolumetricMeasurementSource source);
    void setVolumetricOverride(bool override) { volumetricOverride = override; }
    bool isBluetoothScaleHealthy() const;
    bool waitForScaleTare(unsigned long timeoutMs, float tolerance);
    void onFlush();
    int getWaterLevel() const {
        float reversedLevel = static_cast<float>(settings.getEmptyTankDistance()) -
                              static_cast<float>(std::min(settings.getEmptyTankDistance(), tofDistance));
        return static_cast<int>((reversedLevel - settings.getFullTankDistance()) /
                                static_cast<float>(settings.getEmptyTankDistance() - settings.getFullTankDistance()) * 100.0f);
    };

    void onVolumetricDelete();
    bool isLowWaterLevel() const { return getWaterLevel() < 20; };

    SystemInfo getSystemInfo() const { return systemInfo; }

    NimBLEClientController *getClientController() { return &clientController; }

  private:
    // Initialization methods
#ifndef GAGGIMATE_HEADLESS
    void setupPanel();
#endif
    void setupBluetooth();
    void setupInfos();
    void setupWifi();

    // Functional methods
    void updateControl();

    // Event handlers
    void onTempRead(float temperature);

    // brew button
    void handleBrewButton(int brewButtonStatus);

    // steam button
    void handleSteamButton(int steamButtonStatus);
    void handleProfileUpdate();

    // Private Attributes
#ifndef GAGGIMATE_HEADLESS
    DefaultUI *ui = nullptr;
    Driver *driver = nullptr;
#endif
    NimBLEClientController clientController;
    hw_timer_t *timer = nullptr;
    Settings settings;
    PluginManager *pluginManager{};
    ProfileManager *profileManager{};

    int mode = MODE_BREW;
    float currentTemp = 0;
    float pressure = 0.0f;
    float targetPressure = 0.0f;
    float currentPuckFlow = 0.0f;
    float currentPumpFlow = 0.0f;
    float targetFlow = 0.0f;
    int tofDistance = 0;

    SystemInfo systemInfo{};

    Process *currentProcess = nullptr;
    Process *lastProcess = nullptr;

    unsigned long grindActiveUntil = 0;
    unsigned long lastPing = 0;
    unsigned long lastProgress = 0;
    unsigned long lastAction = 0;
    bool loaded = false;
    bool updating = false;
    bool autotuning = false;
    bool isApConnection = false;
    bool initialized = false;
    bool screenReady = false;
    bool waitingForController = false;
    unsigned long connectStartTime = 0;
    bool volumetricOverride = false;
    bool processCompleted = false;
    bool steamReady = false;
    bool sdcard = false;
    int error = 0;

    // Bluetooth scale connection monitoring
    VolumetricMeasurementSource currentVolumetricSource = VolumetricMeasurementSource::INACTIVE;
    unsigned long lastBluetoothMeasurement = 0;
    double lastVolumetricMeasurementValue = 0.0;
    static const unsigned long BLUETOOTH_GRACE_PERIOD_MS = 1500; // 1.5 second grace period
    static const unsigned long CONTROLLER_WAITING_TIMEOUT_MS = 10000;

    xTaskHandle taskHandle;

    static void loopTask(void *arg);
};

#endif // CONTROLLER_H

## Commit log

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2024-10-26 feat: Refactoring, reduce size, fix ui bug
    [Controller.cpp, Controller.h]
2024-10-27 fix: Fix hot water function
    [Controller.cpp]
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2024-10-28 fix: Fix relay function
    [Controller.cpp]
2024-10-28 fix: Fix new pump logic
2024-10-28 fix: Try fix steam
    [Controller.cpp]
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2024-10-30 feat: Add settings screen, temperature offset, fix UI
    [Controller.cpp, Controller.h]
2024-10-30 feat: Add wifi and bluetooth indicator Fixes #3
    [Controller.cpp]
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2024-10-31 fix: Fix PCB buttons, traces
    [Gaggimate.kicad_pcb, Gaggimate.kicad_sch]
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2024-10-31 fix: Fix index_html rendering
    [Controller.cpp]
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2024-11-04 feat: Replace diodes with usb protection chip
    [Gaggimate.kicad_pcb, Gaggimate.kicad_sch]
2024-11-07 fix: Conditionally enable homekit
    [Controller.cpp]
2024-11-07 fix: Don't run loop before setup
    [Controller.cpp, Controller.h]
2024-11-08 fix: add clang-tidy fix
    [Controller.cpp]
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2024-11-15 feat: Fix PCB label, add render
    [Gaggimate.kicad_pcb, Gaggimate.kicad_sch]
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2024-11-21 fix: Add more footprints for pinout
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2024-11-22 feat: Replace 10uF output capacitor with 22uF
    [Gaggimate.kicad_pcb, Gaggimate.kicad_sch]
2024-11-23 feat: Add grinding feature
    Fixes #6
    [Controller.cpp, Controller.h, Settings.h]
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2024-11-24 fix: Exchange switch for correct model
    [BOM-Gaggimate.csv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]
2024-11-24 fix: Move back connectors to allow expansion to fit
    [BOM-Gaggimate.csv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]
2024-11-24 fix: Retract ground plane a bit
    [Gaggimate-CuBottom.gbr, Gaggimate-CuTop.gbr, Gaggimate-EdgeCuts.gbr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]
2024-11-24 fix: Fix AC line
    [Gaggimate-CuBottom.gbr, Gaggimate-CuTop.gbr, Gaggimate-EdgeCuts.gbr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]
2024-11-24 fix: Fix via in pad
    [Gaggimate-CuBottom.gbr, Gaggimate-CuTop.gbr, Gaggimate-EdgeCuts.gbr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]
2024-11-26 chore: Fix sonarqube issues #1
    [Controller.cpp, Controller.h]
2024-11-26 chore: Fix sonarqube issues #2
2024-11-26 chore: Fix sonarqube issues #3
2024-11-26 chore: Fix sonarqube issues #4
    [Controller.cpp]
2024-11-26 chore: Fix sonarqube issues #5
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2024-11-27 feat: Rework OTA library, use SPIFFS for web
    [Controller.cpp]
2024-11-27 fix: Fix sonarqube errors
2024-11-27 fix: Fix more sonarqube errors
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2024-11-28 feat: Replace entire Web UI with PReact app
    [Controller.h]
2024-12-02 feat: Add missing components to BOM
2024-12-02 fix: Fix pinout diagram for new PCB layout
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2024-12-02 feat: Add clipped pcb case to avoid screws and heatsets
    [pcb_clipped_base.stl, pcb_clipped_cover.stl]
2024-12-11 fix: Fix rotation calculation
    [Controller.cpp]
2024-12-17 fix: Remove slow animations, fix lvgl settings, fix slow AP mode
    [Controller.cpp, Controller.h]
2024-12-18 fix: Fix losing duration on water screen
    [Controller.cpp]
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2025-01-11 feat: Use flex for menu, unload screens
    [Controller.cpp, Controller.h, utilities.h]
2025-01-14 feat: Rework UI, add waveshare driver, add BLE preparation
    [Controller.cpp, I2C_Driver.cpp]
2025-01-17 fix: Fix waveshare driver
    [WavesharePanel.cpp, utilities.h]
2025-01-17 fix: Add working waveshare 2.8 inch driver
    [WavesharePanel.cpp, utilities.h]
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2025-01-25 fix: Fix pid bug with temp offset
    [Controller.cpp]
2025-01-30 fix: Fix double call to target volume
    [Controller.cpp]
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2025-02-01 fix: Fix averaging flow
2025-02-01 fix: Fix boiler fill event on startup
    [Controller.cpp]
2025-02-01 Fixed case-typo
2025-02-01 fix: Fix sonarqube findings
2025-02-01 fix: Fix sonarqube issue
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2025-02-05 fix: Fix predictive flow
2025-02-11 fix: Cleanup before board v2
    [BOM-Gaggimate.csv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]
2025-03-15 feat: Add button control (#139)
    * added brew button on
    * brew button functionality
    * added steam button actions
    * revert dev changes
    * revert
    * feat: Finish button control code
    * chore: Reformat code
    * fix: Rename button methods
    ---------
    [Controller.cpp, Controller.h, Settings.h]
2025-03-15 feat: Add predictive shutoff for weight based brewing (#140)
    * feat: Add shutoff and volume rate prediction (#106)
    * changed prediction to linear fit to last n (default 2) measurements and use actual measurement time
    * moved calculation to reduce number of calls
    * store measurements; first small changes for delay calculation
    * fixes
    * switched to time window for prediction, updated GrindProcess
    * small edits
    * some edits/fixes
    * added update of delays 2s after processes become inactive
    * moved linear fit to a new header file
    * feat: Rework predictive code
    ---------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
    [Controller.cpp, Settings.h]
2025-03-15 feat: Start reworking controller code, move it into sub-project (#46)
    * feat: Start reworking controller code, move it into sub-project
    * feat: Add board autodetection
    * chore: Fix build, format
    * feat: Add new board version
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2025-03-16 feat: Rework OTA, allow flashing controller (#148)
    * feat: Rework OTA, allow flashing controller
    * fix: Add fixes for OZTA
    * fix: Fix issues with OTA
    [Controller.cpp, Controller.h]
2025-03-16 feat: Raise weight output limit to 250 (#149)
    Fixes #138
    [constants.h]
2025-03-17 feat: Rework everything into peripherals (#150)
    * feat: Raise weight output limit to 250
    * feat: Move everything into peripherals
    Fixes #78
    * fix: Remove unnecessary commentsg
    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
    [Controller.cpp]
2025-03-17 feat: Add pressure and dimmer peripheral (#151)
    * feat: Add pressure and dimmer peripheral
    Fixes #87
    * fix: Add back version
2025-03-17 fix: Fix captive portal (#152)
    * fix: Fix captive portal
    * fix: Remove unused HTML
    [Controller.cpp, Controller.h]
2025-03-17 fix: Fix wifi bug
    [Controller.cpp]
2025-03-18 fix: Fix OTA, protocol errors, scale prediction (#154)
    * fix: Fix OTA, protocol errors
    * chore: Format, remove debug logging
    * fix: Fix scale prediction logic
    [Controller.cpp, Controller.h]
2025-03-19 fix: Add LPF for heater
2025-03-19 fix: Disable heater on timeout
2025-03-19 fix: Fix heater, add debug logging
2025-03-19 feat: Fix v1.4.0 bugs, add better scale and grind control (#158)
    [Controller.cpp, Settings.h]
2025-04-01 WebUI & OTA Overhaul (#166)
    * feat: Overhaul Web UI, improve OTA
    * fix: Add more components for profiles
    * fix: Skip one auto OTA
    * fix: Fix delay
    [Controller.cpp]
2025-04-01 feat: Automatically run autotune on machine startup (#167)
    * feat: Automatically startup heater in autotune mode
    * fix: Fix board value
2025-04-01 fix: Switch back to PID loop
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2025-04-06 feat: Fix pressing through wakeup, adjust button borders (#170)
2025-04-06 feat: Allow setting timezone via Web UI (#171)
    * feat: Fix pressing through wakeup, adjust button borders
    * feat: Allow setting the timezone via Web UI
    [Controller.cpp, Settings.h, constants.h]
2025-04-06 feat: Make standby timeout configurable (#172)
    Fixes #120
    [Controller.cpp, Settings.h, constants.h]
2025-04-07 feat: Add error display, update display, controller reconnect (#174)
    Fixes #4, #61
    [Controller.cpp]
2025-04-10 feat: Add PID Autotune (#176)
    * feat: Add profile edit screen
    * feat: Add PID Autotune
    * fix: Hide future menu options again
    * fix: Remove unused css
    [classicpro.bom.tsv]
2025-04-15 fix: Fix some bugs
    [Controller.cpp]
2025-04-22 fix: Change stl files for pcb enclosures
    [pcb_base_clipped.stl, pcb_cover_clipped_[support].stl]
2025-05-19 fix: Fix PID heater
2025-05-21 fix: Fix nightly bugs
    [constants.h]
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2025-05-29 feat: Improve/fix pump on standard v2, cleanup BLE comms (#210)
2025-06-03 Add Feature: customize pressure sensor scaling (#225)
    * feat: Try out Nimrod PID library
    * Fix for acaia pearl s scale
    * quick hack for 12 bar pressure sensor
    * Revert "feat: Try out Nimrod PID library"
    This reverts commit b539c8980746967338ea3cfbfa956cf69a72c57c.
    * Revert "quick hack for 12 bar pressure sensor"
    This reverts commit f4b5a6e22afaea68f35b8dac588118365b2ae321.
    * Added a setting for 12/16 bar pressure sensor; change to this setting requires reboot.
    * changed to manual entry on web page, fixed value not being saved, value is still not being properly set.
    * Changed data type from byte array to string representation of float value when sending pressureScaling between clien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
    [Controller.cpp, Controller.h, Settings.h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]
2025-06-03 feat: Try out Nayrods PID library (#223)
    * fix: Rename PID lib
    * feat: Publish artifacts to GH-pages
    * fix: Fix PR workflow
    * fix: Fix case
    * feat: Add required confirmations as controllable
    * fix: Fix simplepid setpoint filter
    * Update Nayrod PID (#226)
    * Add user tunner parameter/ changed thresholds for autotune+safety detection/tested setpoint filter and feedforward
    * Autotune calculation
    * Switch setpoint filter for second order filter
    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
2025-06-03 fix: Remove extra options from pid
2025-06-03 fix: Fix default PID values
    [constants.h]
2025-06-06 feat: Introduce profiles (#175)
    * fix: Fix merge errors
    * feat: Add new profile screen
    * fix: Fix PID heater
    * feat: Add profile progress
    * feat: Repair code after cherrypicking, finish touch ui, add migration
    * feat: Tune pump control, extend protocol
    * feat: Add functioning web ui
    * feat: Add web ui fixes, reflect profile on screen
    * feat: Add favorite function
    * fix: Fix communication
    * feat: Finalize profiles with pressure
    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
    [Controller.cpp, Controller.h, Settings.h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]
2025-06-06 fix: Add improved pump control
2025-06-06 fix: Fix null division bugs
    [profile.h]
2025-06-09 fix: Revert changes to pump
2025-06-12 fix: Fix BLE communication delays (#239)
    * fix: Fix BLE communication delays
    * fix: Fix wrong import
    [Controller.cpp, Controller.h]
2025-06-14 fix: Fix waveshare panel
    [WavesharePanel.cpp]
2025-06-14 Pressure scaling UI fixes (#235)
    * feat: Introduce profiles (#175)
    * Revert "feat: Introduce profiles (#175)"
    This reverts commit 27d7e809706613b02c70ae091e312954ae1913ea.
    * Adjust UI pressure scale gauge with pressure scaling factor stored in settings.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
2025-06-15 fix: Fix pump power, grind volume setting
    [Controller.cpp, constants.h]
2025-06-16 feat: Add Nayrods pump control, flow estimation and volume estimation (#251)
    * feat: Add Nayrods pump control, flow estimation and volume estimation
    * fix: Fix test warning
    * fix: Fix volume estimation
    * feat: Add pressure and flow graphs to web ui
    * fix: Fix controller usage
    [Controller.cpp, Controller.h]
2025-06-16 fix: Fine-tune new pump library
2025-06-16 fix: Try fix wifi issues
    [Controller.cpp]
2025-06-27 Feature/standby brightness reduction (#266)
    * cpp side impl
    * webui side
    * Fix bad unstash
    * Add zero standby brightness
    * Claude to include a toggle
    * Move standby brightness handling to updateStandbyScreen
    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
    [Settings.h]
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2025-06-27 Further enhance pump controls (#273)
    * feat: Pump precision (#264)
    * Improve overshoot and time response of pressure control
    * Fixed virtualscale flow spikes and zero artefact in virtualscale() function
    * changed OPVValve to valve
    * Fixed error in antiwindup
    * fix: Fix freertos calls
    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
2025-06-29 feat: Steam Rework and temperature indicator (#277)
    * feat: Redesign UI for new steam mode
    * Make it green (when ready) (#272)
    * feat: Add UI Changes
    * feat: Make steam pump percentage adjustable
    * feat: Change button control for steam mode
    * feat: Major UI speedup, add auto steam
    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
    [Controller.cpp, Controller.h, Settings.h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]
2025-06-30 fix: Fix settings for volumetric target and pressure
    Fixes #270, #275
2025-06-30 fix: Make pressure bar smoother
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2025-07-09 Implement async WiFi manager (#293)
    * Refine WiFi manager and restart network services
    * fix: Fix wifi manager issues, deprecations
    [Controller.cpp, Controller.h, LilyGo_RGBPanel.cpp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]
2025-07-09 fix: Fix wrong flow when no brew is running
2025-07-10 fix: Initialize wifi last
    [Controller.cpp]
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2025-07-10 fix: Fix too verbose error logging
    [Controller.cpp]
2025-07-11 fix: Replace wifi manager
    [Controller.cpp, Controller.h]
2025-07-13 fix: Improve heater safeguards (#304)
2025-07-13 feat: Revert wifi manager, use simple wifi
    [Controller.cpp, Controller.h, constants.h]
2025-07-14 fix: Use log tag in controller
    [Controller.cpp, Controller.h]
2025-07-14 Add display theme application via WebUI (#282)
    * Add theme application
    * Revert SLS edit
    * Fix newlines
    * Fix settings, change colors
    * No need to trigger dirty
    [Settings.h]
2025-07-14 fix: Fix pump calls, send pump flow rate
2025-07-14 feat: Add first shot on history (#297)
    * feat: Add first shot on history
    * fix: Fix too verbose logging
    * fix: Fix too verbose error logging
    * feat: Finish first shot of shot history
    * fix: Fix data change
    * fix: Fix estimator
    [Controller.cpp, Controller.h, Settings.h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]
2025-07-16 Changed ESP_PANEL_LCD_RGB_TIMING_FREQ_HZ (#306)
    * Update BLEScalePlugin.cpp for WeighMyBru Scale Support
    * Added WeighMyBru Scale Support & Updated platformio.ini
    * Add GitHub Pages firmware flasher
    * Fixed URL for flashing
    * Auto-update firmware files [skip ci]
    * Auto-update firmware files [skip ci]
    * Fixed OTA URL
    * Auto-update firmware files [skip ci]
    * Update OTA system to point to fork and add complete firmware files
    - Modified OTA URL in WebUIPlugin.h to point to fork instead of original repo
    - Updated GitHub link in web UI Header.jsx
    - Added complete firmware files for OTA: display-firmware.bin, display-filesystem.bin, board-firmware.bin
    - Built and included SPIFFS filesystem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
    [utilities.h]
2025-07-17 Move Save Preferences button on OTA page and fix overflow issues (#305)
    * move "Save preferences" button on OTA page, fix overflow issues on OTA and Settings page
    The only real changes are to /web/src/pages/OTA/index.jsx and /web/src/pages/Settings/index.jsx, the rest are from running the prettier command
    Moved the "Save preferences" button to the div containing the Update channel selector to clarify that the button saves the update channel chosen
    Added flex-wrap and gap-y-2 to the div containing the Update-buttons to allow the buttons to stack vertically when there is not enough width to stack them horizontally
    * change flex gap to gap-y-1 on container for Update-buttons to match gap be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
2025-07-17 fix: Fix buttons on mobile devices
2025-07-23 Tailwind and Vite upgrade (#318)
    * update vite
    * Upgrade TailwindCSS and Vite
    Upgraded to Tailwind v4
    Upgraded to Vite v7
    Removed PostCSS as its no longer required by tailwind
    updated styles to conform to tailwind requirements not totally sure what you want on the border as border-opacity is depreciated
    * Updated to per CodeRabbit
    this is how i tried it originally and it didn't work but idk it does now.
    * Update package.json
    * Add back safelist and font family.
    Also remove flowbite as its not used.
2025-07-23 fix: Add back smoothing in pressure controller (#319)
2025-07-26 feat: Allow flow control with pressure limit (#320)
    * feat: Allow flow control with pressure limit
    * fix: Cleanup unused code
    * feat: Allow controlling flow from profile
    * fix: Add codereview feedback
    * fix: Fix unused variable
    * fix: Fix flow control to use pump not puck flow
    * feat: Add UI for flow
    * fix: Small fixes to pressure controller
    * fix: Remove console.log
    * fix: Fix wrong attribute
    * fix: Fix volumetric target
    [Controller.cpp]
2025-07-27 fix: Feed back manual control into pressure controller (#324)
2025-07-27 Implement support for 1.43 inch LilyGo T-Display S3 AMOLED (DS) (#218)
    * Add the board
    * Basic Panel, Drivers and LVGL support
    * True black for amoled
    * BLE mocks until I get the controller board
    * Add rotation to T-Display
    * Add sleep/wakeup routines
    * Subclass CO5300 and add color order functions
    * Return correct ID in getModel
    * Remove S3-AMOLED board as it is identical to T-RGB
    * Add battery voltage reading (just in case)
    * Streamline board identification
    * Rearrange touch driver init
    * Fix typo
    * Fix samples read in getBattVoltage
    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
2025-07-29 fix: Fix smoothing of flow
2025-07-29 fix: Try smooth down pressure control
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2025-08-12 fix: Debug steam flow
    [Controller.cpp]
2025-08-12 fix: Fix pump flow multiplier
    [Controller.cpp]
2025-08-12 fix: Fix reset logic for Waveshare 2.1 screen
    [WavesharePanel.cpp]
2025-08-12 fix: Add reset for touch driver
    [WavesharePanel.cpp]
2025-08-12 fix: Fix waveshare screen dimming
    [WavesharePanel.cpp, utilities.h]
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2025-08-13 Daisy UI Migration (#355)
    * Add Daisy Ui (#339)
    * Initial Daisy Ui transition and 4 themes to start
    * Update Ui
    * Fix SonarCloud issues
    * Remove Computed Single line Chart Register
    * Use JSX syntax
    * Apply Bunny Fixes
    * Use card component
    * Use Card
    * Fix active and hover states
    * Format and Style Nav Bar Better
    * Move profiles over(need to fix spacing between lables)
    * Fix Mobile Layout
    * Fix mobile layout
    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
2025-08-13 fix: Fix momentary buttonsg
    [Controller.cpp]
2025-08-14 Update BLEScalePlugin.cpp for Aliexpress myscale support (#353)
    * Update BLEScalePlugin.cpp for Aliexpress myscale support
    Added call to myscale Aliexprss cheap scale in conjunction with https://github.com/gaggimate/esp-arduino-ble-scales/pull/11
    * Fixed issue where the bluetooth scale was taring too late (at brew start).
    If the scale had a higher value than the voulumetric setpoint at start,
    the tare would not happen in time and the brew would finish.
    The controller now tares the bluetooth scale before starting the brew and at the same time as it issues controller->tare() to the hardware scale.
    [Controller.cpp]
2025-08-15 fix: Add web app manifest, fix estimated volume export
    [Controller.cpp]
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2025-08-17 Add advanced profiles (#365)
    * feat: Add schema changes for advanced profiles
    * feat: Add exit conditions and temperature profiling
    * feat: Separate process classes
    * chore: Reformat
    * feat: Add transitions
    * fix: Add code review feedback
    * fix: Allow bigger size profiles, allow foreign profile formats
    * feat: Extend web ui to allow editing pro profiles
    * fix: Fix new profile rendering
    * feat: Add decent profile import
    * fix: Don't ramp limit
    * fix: Fix profile chart
    * feat: Add transition and temperature config to UI
    * fix: Fix adaptive setting
    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
    [Controller.cpp, Controller.h, LedControlPlugin.cpp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]
2025-08-17 fix: Fix phase temperature
    [profile.h]
2025-08-21 fix: Fix deleting cancelled shots, weight flow
2025-08-21 fix: Switch NTP logic
2025-08-21 fix: Treat temps as float
    [Controller.cpp, Controller.h]
2025-08-21 fix: Fix compile warnings
    [Controller.cpp]
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2025-08-21 fix: Fix critical sonarqube issues
2025-08-21 fix: Revert heating indicator to green/red
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2025-08-21 fix: Fix compile errors
    [Settings.h]
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2025-08-22 Add move up/down functionality and persist profile order (#377)
    * Add move up/down functionality for profile cards
    * Persist reordering of profiles
    * Fix PR comments
    * Minor cleanup in Settings.cpp
    Makes the code a bit easier to read.
    * Add aria-disabled to move-buttons.
    [Settings.h]
2025-08-22 fix: Use either time or volumetric logic for standard profiles
    [profile.h]
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2025-08-23 fix: Skip PWM logic for 0/100 setting of simple pump
2025-08-23 fix: Fix formatting of steam pump percentage field
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2025-08-25 fix: Switch back to 250ms telemetry
2025-08-25 fix: Fix variation between virtual scales and puck flow
2025-09-03 Add short timeout to switchover from BLE Volume to Estimated Volume (#406)
    * Optimize
    * Reduce grace period
    [Controller.cpp, Controller.h]
2025-09-03 fix: Fix volume estimation in stable
    [Controller.cpp]
2025-09-03 fix: Calculate bluetooth flow at fixed intervals (#407)
    * fix: Calculate bluetooth flow at fixed intervals
    * fix: Reformat, fix issues
2025-09-03 fix: Improve flow estimation
2025-09-08 Nightly (#410)
    * Enhanced pressure control and raw estimator
    * .h missing
    * Basic flow estimator
    * fix: Fixed coffee weight estimator
    - Cleaned unused variables
    - Fixed estimator for accurate flow estimation (need to tune the first drip criteria)
    * First drip criteria adjustable, set to 38g by default
2025-09-16 Nightly (#419)
    * Fix: Reset variables with tare
    Feat: First drop set on puck conductance derivative criteria
    * Tweaked filtering
    * Fix: Puck flow filter force resetting
    Tuned puck flow filter
    * Fix: Filtered flow reused instead of going from raw
    added another variable for output filtered pump flow
    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
2025-09-16 fix: Change steam cutoff default
    [constants.h]
2025-09-17 Revert "fix: Update version comparison logic to allow updates from nightly to…" (#426)
    This reverts commit 261c42c4949723b8200b78a017a1d74196f6ddc5.
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2025-09-29 fix: Fix switching volumetric source while running a shot (#439)
    * fix: Fix switching volumetric source while running a shot
    * fix: Allow skip pr-flash
    * fix: Resolve pr feedback
    * fix: Resolve pr feedback
    [Controller.cpp, Controller.h]
2025-10-01 Optimize/shot history + Storage indicator in system & updates (#441)
    * Overview
    The previous CSV history format has been replaced by a compact binary format written directly to SPIFFS to reduce CPU time and flash wear from frequent string allocations / formatting. Each shot is recorded at ~250 ms intervals. All fields are always present in each sample.
    Incomplete / Interrupted Shots
    If the device reboots or the shot is otherwise interrupted before finalization, `sampleCount` and `durationMs` remain 0 in the header. Recovery logic:
    - Listing (`req:history:list`) infers `samples` and `duration` by: `(fileSize - headerSize) / sampleSize` and reading the last full sample's `t`.
    - Binary downloa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
2025-10-05 Shot history index and front-end search tools (#449)
    * - Fix history endpoint to /api/history
    - Don't process incomplete shots on the back-end, process on the front and show incomplete badge
    - Delay loading shot notes until expanded
    - Add weight to shot log header / list
    * - Add shot history index and serve to webui for fast listing of many shots
    - Merge note data into the index (weight, rating) for display
    - Early index entry created >7.5s to account for possible interruptions
    * Add sorting, filtering, searching and pagination to the shot history page.
    Fix some formatting issues.
    * Use fontawesome +/- for expand/collapse
2025-10-05 fix: Fix grind not shutting off
    [Controller.cpp]
2025-10-05 fix: Fix esp-arduino-ble-scales dep
2025-10-05 Auto-warmup scheduler with per-day scheduling (#387)
    * Remove backwards compatibility checks (old style without days wasn't used except for testing)
    Clean up UI and make it more compact
    * Remove clock icon from time input fields to reduce width of field
    * Change time field to auto width and remove clock icon to minimize space.
    * Revert css change to hide time input clock icon as some platforms require it for input.
    * Increase time field width to better fit the time input icon.
    * Move auto wakeup schedule settings to the bottom plugin section
    [Controller.cpp, Settings.h]
2025-10-08 Overview chart - show profile phases during brew (#450)
    * - Add profile phase markers on overview chart
    - Adjust time axis to show more detail during shot and zoom out as needed
    * - stabilize x-axis
    - ui tweaks
    * Adjust padding
